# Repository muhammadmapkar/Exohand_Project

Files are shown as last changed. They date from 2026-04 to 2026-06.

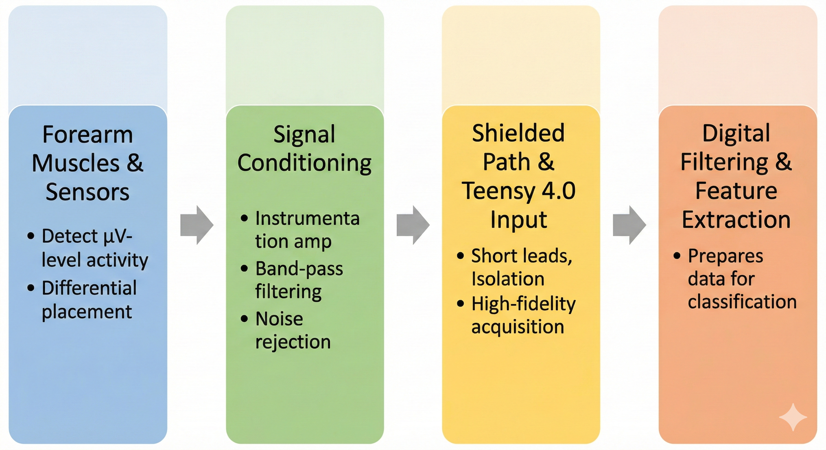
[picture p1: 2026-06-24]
media/Gemini_Generated_Image_888kaw888kaw888k.png

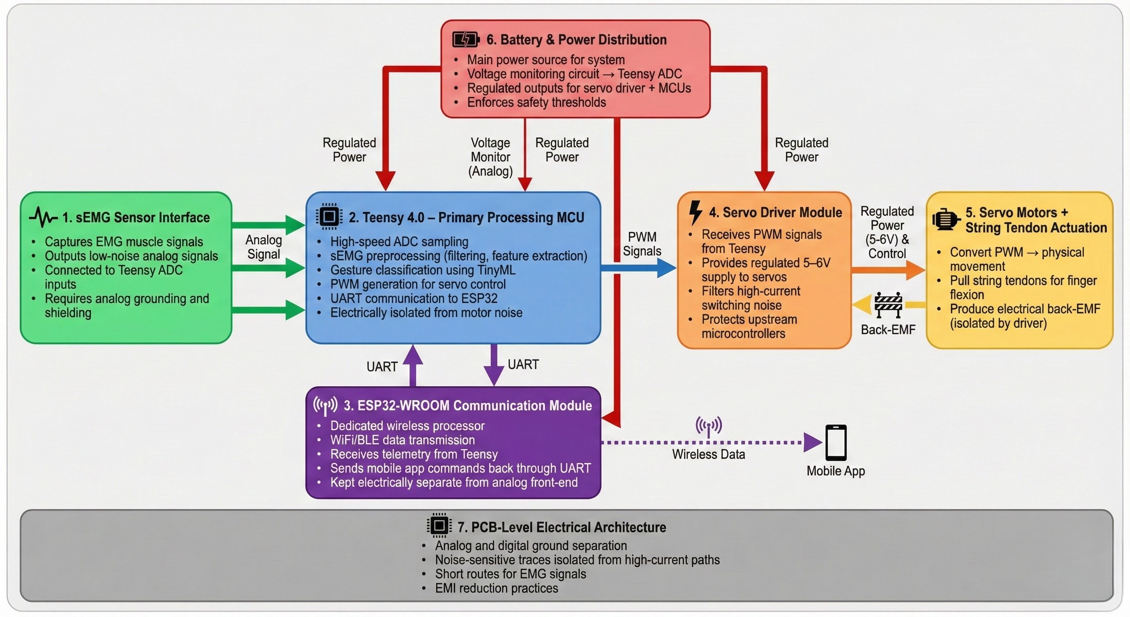
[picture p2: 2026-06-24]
media/Gemini_Generated_Image_9dc1pz9dc1pz9dc1~2.jpg

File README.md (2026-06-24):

# ExoHand

EMG-controlled assistive robotic hand. Built for ECTE351 by Team Orvyn (Group 19).

## Overview

ExoHand reads surface EMG (sEMG) from the forearm, classifies the muscle activity into a hand gesture, and drives four servo-actuated fingers to match. The current system recognizes `rest`, `fist`, and individual-finger gestures (`pinky&ring`, `middle`, `index`, `thumb`), running the trained classifier directly on the microcontroller. VR integration is planned; not yet in this codebase. — see `docs/architecture.md`. Runs the trained classifier on-device (no PC needed for inference).

## EMG-control concept

1. Sample raw EMG at 1 kHz from a single sensor channel.
2. Extract statistical features (MAV, RMS, variance, std dev, waveform length, zero-crossing rate, slope sign changes, skewness, kurtosis, IQR) over a rolling 30-sample window.
3. Classify the window with a Random Forest trained on EMG collected by the team (plus validation against the public NinaPro benchmark dataset).
4. Debounce the result (4 agreeing windows + 150ms hold) before committing to a new gesture.
5. Drive 4 servos through a PCA9685 to match the confirmed gesture, moving smoothly rather than snapping.

Full signal-flow diagram: `docs/architecture.md`.

## Hardware stack

- Teensy 4.0 — main MCU for EMG sampling, feature extraction, and on-device RF inference
- PCA9685 servo driver (I2C, 4 channels)
- MG996R servos (or equivalent)
- SEN0240 EMG sensor
- ESP32-C3, for live telemetry/graph relay (`firmware/current/esp32_bridge.ino` — self-hosted WiFi AP + WebSocket server)

## Repo layout

```
exohand/
├── firmware/        Teensy/ESP32 .ino code — current/ is what's in active use, archive/ is superseded versions
├── web/             static site + the FastAPI live dashboard
├── hardware/        KiCad schematics/PCB, BOM, perfboard build docs
├── signal-processing/  EMG filtering, feature extraction, trained model, datasets
├── docs/            build-log, architecture, decisions, posters
└── media/           screenshots, recordings, concept art
```

Nothing failed or superseded was deleted — old firmware versions, every dated PCB backup, duplicate dataset exports, and earlier notebook runs are all kept under the relevant `archive/` folders. See `docs/build-log.md` for the full story of what was tried and what changed.

## How to build / run

**Firmware:** open `firmware/current/teensy_final.ino` in Arduino IDE with Teensyduino (board: Teensy 4.0), plus the Adafruit PWM Servo Driver and Watchdog_t4 libraries. It includes `ai_classifier_model.h`, which is checked into `firmware/current/` and compiles as-is. To regenerate it from a retrained model, run `python3 signal-processing/export_model_to_header.py` (loads `ExoHand_RF_Model.joblib` + `ExoHand_Scaler.joblib`, writes the header back to `firmware/current/ai_classifier_model.h`).

**Signal processing / training:** `pip install -r signal-processing/requirements.txt`, then `signal-processing/ExoHand_EMG_Classifier_RF_V2.ipynb` to retrain, or `signal-processing/live_predict.py` to run live PC-side inference over serial.

**Live dashboard:** `web/dashboard/app.py` (FastAPI). Install `web/dashboard/requirements.txt`, run with `uvicorn app:app`, open the browser page it serves. Includes a `/api/demo` mode that fakes EMG data if no hardware is connected.

**Website:** `web/website.html` is the current main site (Live Rehab dashboard view, live EMG chart, camera-based sensor-placement assistant). `web/archive/ORVYNUpdated.html` is an earlier, less developed version.

**Hardware:** schematics and PCB in `hardware/schematics/`, BOM in `hardware/bom/`, perfboard wiring/assembly in `hardware/perfboard/`.

## Credit

Team Orvyn (Group 19). My role: led firmware (Teensy), EMG signal processing, hardware build. Data collection was team effort. Benchmark data from NinaPro.

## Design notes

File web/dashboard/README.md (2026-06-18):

# ExoHand Live EMG Gesture Dashboard

Real-time browser-based dashboard that reads EMG signals from a **Teensy 4.0** via serial, classifies hand gestures using a pre-trained **Random Forest** model, and displays predictions live — no terminal interaction required.





---

## 📁 File Structure

```
ExoHand_Live_Dashboard/
├── app.py                        ← FastAPI backend (serial + model + WebSocket)
├── requirements.txt              ← Python dependencies
├── templates/
│   └── index.html                ← Dashboard HTML
├── static/
│   ├── style.css                 ← Dark theme CSS
│   └── app.js                    ← Frontend logic + Chart.js
├── README.md                     ← This file
│
│  (Place these model files here or in the parent directory)
├── ExoHand_RF_Model.joblib       ← Trained Random Forest model
└── ExoHand_Scaler.joblib         ← EMG Input Scaler
```

---

## 1. Place the Model Files

Copy these three `.pkl` files (exported from Google Colab) into **this folder** or its **parent folder**:

| File | Purpose |
|---|---|
| `ExoHand_RF_Model.joblib` | Trained Random Forest classifier |
| `ExoHand_Scaler.joblib` | EMG Input Scaler |

---

## 2. Install Requirements

Open a terminal in this directory and run:

```bash
pip install -r requirements.txt
```

This installs: `fastapi`, `uvicorn`, `websockets`, `pyserial`, `numpy`, `pandas`, `scikit-learn`, `joblib`, `jinja2`.

---

## 3. Upload Teensy Arduino Code

Flash the following code to your **Teensy 4.0** using the Arduino IDE:

```cpp
const int EMG_PIN = A0;

int baseline = 0;

void setup() {
  Serial.begin(115200);

  long total = 0;

  for (int i = 0; i < 500; i++) {
    total += analogRead(EMG_PIN);
    delay(1);
  }

  baseline = total / 500;
}

void loop() {
  int raw = analogRead(EMG_PIN);
  int signal = abs(raw - baseline);

  Serial.println(signal);

  delay(20);
}
```

### What this does:
- Reads the EMG sensor on analog pin **A0**
- Calibrates a baseline from the first 500 samples
- Sends `abs(raw - baseline)` over serial at **115200 baud**
- One numeric value per line, ~50 samples/second (20 ms delay)

---

## 4. Close the Arduino Serial Monitor

> ⚠ **Only one application can access a serial port at a time.**

Before running the dashboard, **close the Arduino Serial Monitor** (or any other program using the serial port). Otherwise the dashboard will fail to connect.

---

## 5. Run the Dashboard

```bash
python app.py
```

Then open your browser at:

```
http://127.0.0.1:8000
```

You should see the ExoHand Live EMG Gesture Dashboard.

---

## 6. Using the Dashboard

1. **Refresh Ports** — Click 🔄 Refresh to detect available serial ports.
2. **Select Port** — Choose the Teensy serial port from the dropdown (e.g. `/dev/cu.usbmodem14101` on macOS).
3. **Connect** — Click ▶ Connect. The dashboard starts reading live EMG data.
4. **Watch Predictions** — The prediction card updates in real time with the classified gesture, confidence percentage, and a colour-coded display.
5. **Live Graph** — The EMG signal chart shows the last 200 samples continuously.
6. **Gesture History** — The last 10 gesture changes are shown with timestamps and confidence.
7. **Disconnect** — Click ■ Disconnect when done.

---

## Demo Mode (No Hardware Required)

If you don't have the Teensy connected, click the **🎮 Demo Mode** button in the connection panel. This generates fake EMG data at ~50 Hz and runs it through the real Random Forest model, so you can verify that the graph, prediction card, gesture history, and all UI elements work correctly.

---

## 7. Troubleshooting

| Problem | Solution |
|---|---|
| **"Could not open port"** | Close the Arduino Serial Monitor. Only one app can use a serial port. |
| **No ports listed** | Check that the Teensy is plugged in via USB. Click 🔄 Refresh. |
| **"Model not found"** | Make sure the `.pkl` files are in this folder or its parent folder. |
| **Graph shows no data** | Ensure the Teensy code is uploaded and printing values. Check baud rate (115200). |
| **Predictions say "Calibrating"** | Wait for 25 samples to fill the sliding window (~0.5 seconds). |
| **Predictions seem wrong** | The model was trained on specific gestures. Ensure your EMG sensor placement matches training conditions. |
| **WebSocket disconnects** | The dashboard auto-reconnects. If persistent, restart `app.py`. |
| **Import errors** | Run `pip install -r requirements.txt` again. |
| **Port permission denied (Linux)** | Run `sudo chmod 666 /dev/ttyACM0` or add your user to the `dialout` group. |
| **Port busy error** | The Arduino Serial Monitor is still open. Close it and try again. |

---

## Diagnostic Endpoints

| Endpoint | Method | Description |
|---|---|---|
| `/api/ports` | GET | List available serial ports |
| `/api/connect` | POST | Connect to a serial port (`{"port": "...", "baud": 115200}`) |
| `/api/disconnect` | POST | Disconnect from the serial port |
| `/api/demo` | POST | Start demo mode (fake EMG data) |
| `/api/test-serial` | GET | Read 10 raw serial values and return them as JSON (for debugging) |
| `/ws/live` | WebSocket | Live EMG + prediction data stream |

---

## Technical Details
 
 - **Sliding window**: 30 samples (~0.6 s at 50 Hz)
 - **Prediction trigger**: Every 5 new samples
 - **Smoothing**: Majority vote over the last 5 predictions
 - **Features extracted**: `MAV`, `RMS`, `Variance`, `Std`, `WL`, `ZCR`, `SSC`, `Skew`, `Kurtosis`, `IQR`
 - **Gestures**: `fist`, `index`, `middle`, `pinky&ring`, `rest`, `thumb`
 - **Backend → Frontend**: WebSocket at `/ws/live` streaming JSON at ~50 Hz

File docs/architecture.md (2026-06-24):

# Architecture

## Signal flow (EMG → Teensy → PCA9685 → servos)

```mermaid
flowchart LR
    EMG["sEMG sensor (SEN0240)\non Teensy A0"] -->|"1 kHz sampling\n(IntervalTimer ISR)"| BUF["30-sample\nrolling window"]
    BUF --> FEAT["Feature extraction\nMAV, RMS, Variance, Std,\nWL, ZCR, SSC, Skew, Kurtosis, IQR"]
    FEAT --> RF["Embedded Random Forest\n(ai_classifier_model.h)\nmajority vote across trees"]
    RF --> DEBOUNCE["Debounce\n(4 agreeing windows,\n150ms min hold)"]
    DEBOUNCE --> GESTURE["Confirmed gesture\nrest / fist / pinky&ring /\nmiddle / index / thumb"]
    GESTURE --> SERVO["Servo target angles\n(4 channels)"]
    SERVO --> PCA["PCA9685 (I2C, 0x40)\n50 Hz PWM"]
    PCA --> M1["Servo: pinky & ring"]
    PCA --> M2["Servo: middle"]
    PCA --> M3["Servo: index"]
    PCA --> M4["Servo: thumb"]
    DEBOUNCE -->|"UART1, 115200 baud"| ESP["ESP32-C3\n(live graph relay)"]
    BUF -->|"raw EMG, every 20ms"| ESP
```

## Two parallel inference paths

The project has two separate ways of running the trained classifier, built at different times and not unified:

```mermaid
flowchart TB
    subgraph training["Offline training (notebook)"]
        DATA["Team-collected EMG\n(datasets/collected)\n+ NinaPro benchmark\n(datasets/benchmark)"] --> NB["ExoHand_EMG_Classifier_RF_V2.ipynb"]
        NB --> MODEL["ExoHand_RF_Model.joblib\nExoHand_Scaler.joblib"]
    end

    subgraph onboard["On-device (current firmware)"]
        MODEL -.->|"converted to C arrays\n(conversion step not saved)"| HDR["ai_classifier_model.h\n(missing from repo)"]
        HDR --> TEENSY["ExoHand_Teensy.ino\nruns RF inference on-chip"]
    end

    subgraph offboard["PC-side (dev/demo tool)"]
        MODEL --> LP["live_predict.py /\nFastAPI dashboard app.py"]
        SERIAL["Serial: raw EMG from Teensy"] --> LP
        LP --> DASH["Browser dashboard\n(WebSocket live graph)"]
    end
```

The on-device path (`ExoHand_Teensy.ino`) is the intended final form — the Teensy classifies and drives servos with no PC required. The PC-side path (`live_predict.py`, the FastAPI dashboard) is a development and demo tool that reads raw EMG over serial and classifies on a laptop instead, useful for visualizing the live signal and testing the model before/without embedding it.

## Hardware stack

- **MCU:** Teensy 4.0
- **Servo driver:** PCA9685, I2C address `0x40`, 50 Hz PWM
- **Servos:** MG996R (or equivalent), 4 channels — pinky&ring, middle, index, thumb
- **EMG sensor:** SEN0240, single analog channel on Teensy `A0` in the current firmware (earlier firmware used 3 channels: flexor/extensor/extra)
- **Wireless telemetry:** ESP32-C3 running `esp32_bridge.ino` — a self-hosted WiFi access point (SSID `ExoHand_Live`) plus a WebSocket server (port 81) that relays serial lines from the Teensy straight to a connected browser. `ExoHand_ESP32.ino`/`ExoHand_ServoTest.ino` are separate servo-test sketches for the ESP32/Teensy side, not the telemetry bridge itself.
- **Power:** 7.4V 2S LiPo, stepped down for servo and logic rails (per project README notes)

## VR integration

A VR integration goal is part of the project's stated direction, but no VR-specific code was found in the files reviewed here. Treat this as a future goal, not a built feature. (Note: `website.html` does include a camera-based "placement" assistant using MediaPipe FaceMesh — a 2D face-landmark guide, likely for sensor placement on the arm/face via webcam. This is AR-adjacent tooling, not a VR integration, and is unrelated to the stated VR goal.)

## Signal processing pipeline (current, on team-collected + benchmark data)

1. Sample EMG at 1000 Hz.
2. Maintain a 30-sample rolling window, advancing in steps of 5 samples.
3. Extract 10 features per window: MAV (scaled), RMS, variance, standard deviation, waveform length, zero-crossing rate, slope sign changes, skewness, kurtosis, IQR.
4. Classify with a Random Forest (hard majority vote across trees).
5. Debounce: require 4 consecutive windows to agree, plus a minimum 150ms hold, before changing the confirmed gesture.
6. Map confirmed gesture to per-finger servo open/closed targets, moving smoothly (3°/step, every 15ms) rather than snapping.

An earlier, simpler pipeline (`Filter_signals.py`, `Exohand_emg_with_filter.ino`) used a 20–450 Hz bandpass filter + 50 Hz notch filter + RMS thresholding for binary rest/active detection, validated against the public NinaPro benchmark dataset. This was the proof-of-concept before moving to the multi-class, team-data-trained classifier described above.

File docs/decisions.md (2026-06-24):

# Key Decisions

**Random Forest over a neural network for gesture classification.** The classifier needed to run on a Teensy MCU with no OS and no heavy ML runtime. A trained Random Forest can be converted into plain C arrays (tree nodes, thresholds, leaf classes) and run as simple `if`/`else` comparisons — no matrix math, no floating-point-heavy inference engine. This is why `ExoHand_Teensy.ino` runs inference as a hard-coded tree-walk (`predictTree` / `classify`) instead of calling out to a model file at runtime.

**Move from single-servo RMS-threshold control to multi-class, multi-finger classification.** The earliest firmware (`Exohand_emg_with_filter.ino`, `exohand_emg_test.ino`) drove one servo based on whether RMS crossed a fixed threshold — workable for a binary "fist or not" gesture, not for isolating individual fingers. The later pipeline (10 hand-engineered features → Random Forest → 4 independent servo channels) was the response to that limitation, trading simplicity for the ability to recognize `rest`, `fist`, and individual-finger gestures (`pinky&ring`, `middle`, `index`, `thumb`).

**Validate the filtering pipeline against a public benchmark before trusting team-collected data.** `Filter_signals.py` was first run against the NinaPro public EMG dataset (`datasets/benchmark`), not the team's own recordings. This let the bandpass/notch/RMS pipeline be checked against known-good reference data before relying on it for the team's own multi-person EMG dataset (`datasets/collected`), which has no independent ground truth to check against.

**Debounce the classifier output rather than act on every window.** A single 30-sample window classification is noisy — `ExoHand_Teensy.ino` requires 4 consecutive windows to agree on the same gesture, plus a 150ms minimum hold time, before changing the servo targets. This trades a small amount of latency for fewer false gesture-switches.

**Smooth servo motion instead of snapping to target angle.** Servos step 3° every 15ms toward their target rather than jumping immediately. This was likely a response to current-spike / mechanical-jolt issues noted as a known challenge in the project README (servo current spikes causing voltage drops).

**PCA9685 I2C driver instead of driving servos directly from MCU PWM pins.** Four servos need four independent PWM channels; routing them through a dedicated I2C PWM driver frees up MCU pins and offloads PWM generation, at the cost of an extra I2C peripheral and address (`0x40`) to manage.

**ESP32-C3 for wireless telemetry instead of adding WiFi logic to the Teensy.** The Teensy handles real-time sampling and inference; UART-bridging the result to a separate ESP32 keeps WiFi/networking code off the time-critical MCU. `esp32_bridge.ino` implements this: it puts the ESP32 into its own WiFi access-point mode and runs a WebSocket server, forwarding lines read from the Teensy over `Serial2` straight to a browser. This is a self-hosted AP rather than joining an existing network, so the dashboard/website has to connect to the ESP32's own WiFi to receive live data — a reasonable choice for a standalone demo, but worth knowing if internet-connected logging is ever needed.

**Custom PCB attempted, perfboard used for the actual build.** The KiCad project went through 20 dated backup snapshots over roughly five months (Nov 2025–Jun 2026), splitting logic and power planes per the design notes. Given the time spent, the team also produced perfboard assembly guides and wiring documentation in parallel — the perfboard appears to be how the hardware was actually built and wired, with the PCB design kept as the longer-term/parallel hardware effort rather than abandoned.

**Keep a PC-side prediction path (`live_predict.py`, the FastAPI dashboard) alongside the on-device firmware.** Running inference on a laptop over serial is slower and requires a tethered connection, but it's much easier to debug and visualize than reading values off an embedded device — useful during development and for the live demo, even though the end goal is fully on-device classification.

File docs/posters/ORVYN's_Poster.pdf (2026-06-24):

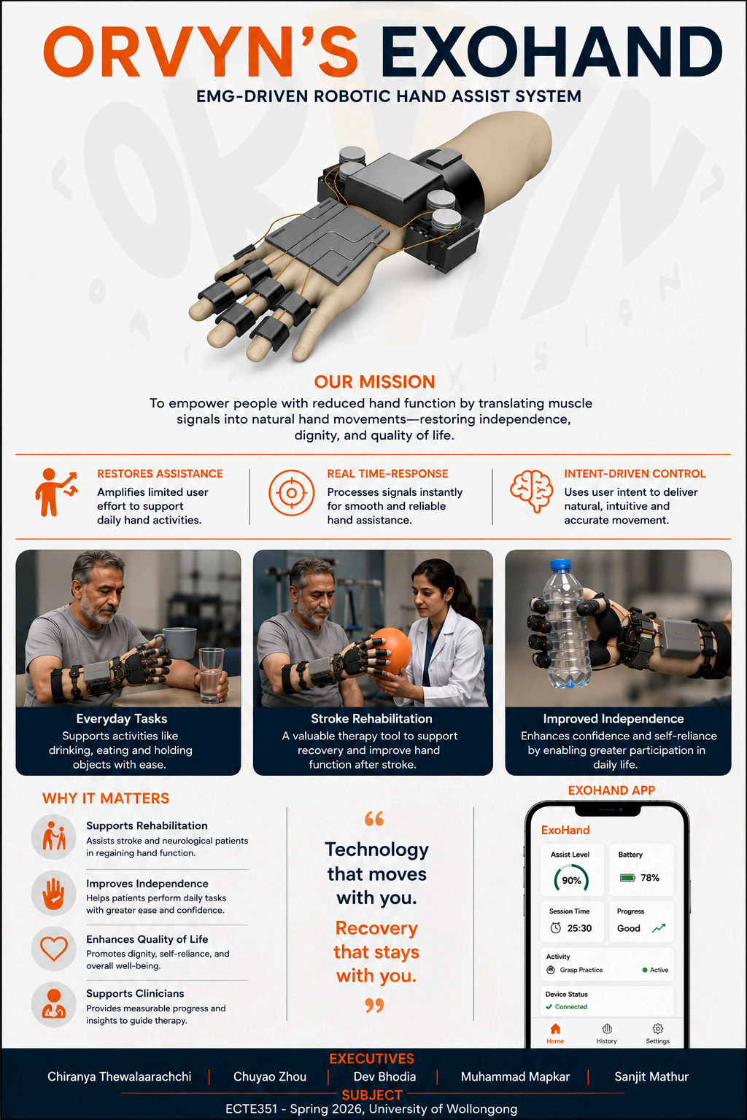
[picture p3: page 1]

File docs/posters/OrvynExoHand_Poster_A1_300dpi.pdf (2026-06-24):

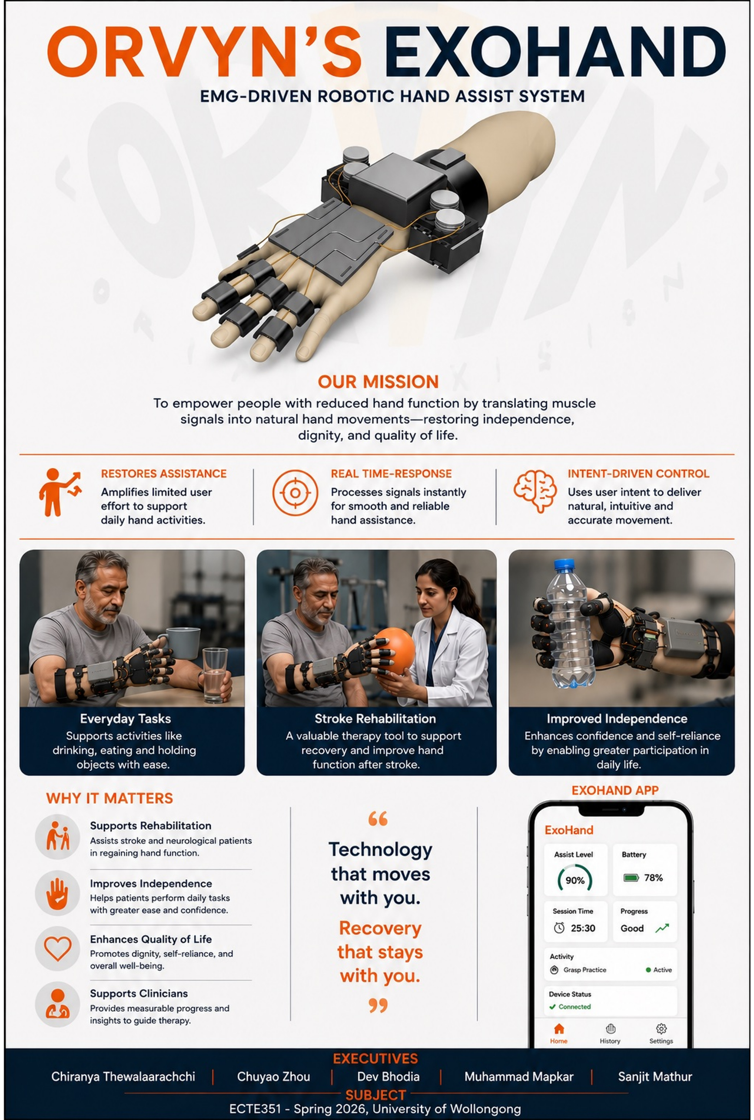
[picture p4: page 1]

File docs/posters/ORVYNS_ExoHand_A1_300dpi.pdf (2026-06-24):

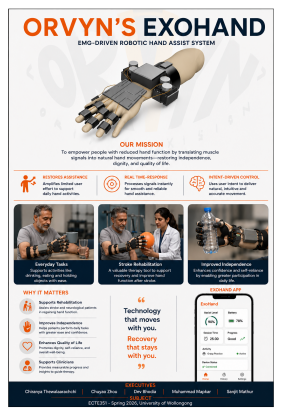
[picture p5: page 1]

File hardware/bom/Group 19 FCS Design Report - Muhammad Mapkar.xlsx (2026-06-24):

 |  | Max mark =30 | Dev | Chuyao | Muhammad | Sanjit | Chiranya
 |  |  | Bhodia | Zhou | Mapkar | Mathur | Thewalaarachchi | Total =100
Name of Person submitting | Dev | Bhodia | 20 | 20 | 20 | 20 | 20 | 100
 | Muhammad | Mapkar | 20 | 20 | 20 | 20 | 20 | 100
 | Chuyao | Zhou | 20 | 20 | 20 | 20 | 20 | 100
 | Sanjit | Mathur | 20 | 20 | 20 | 20 | 20 | 100
 | Chiranya | Thewalaarachchi | 20 | 20 | 20 | 20 | 20 | 100

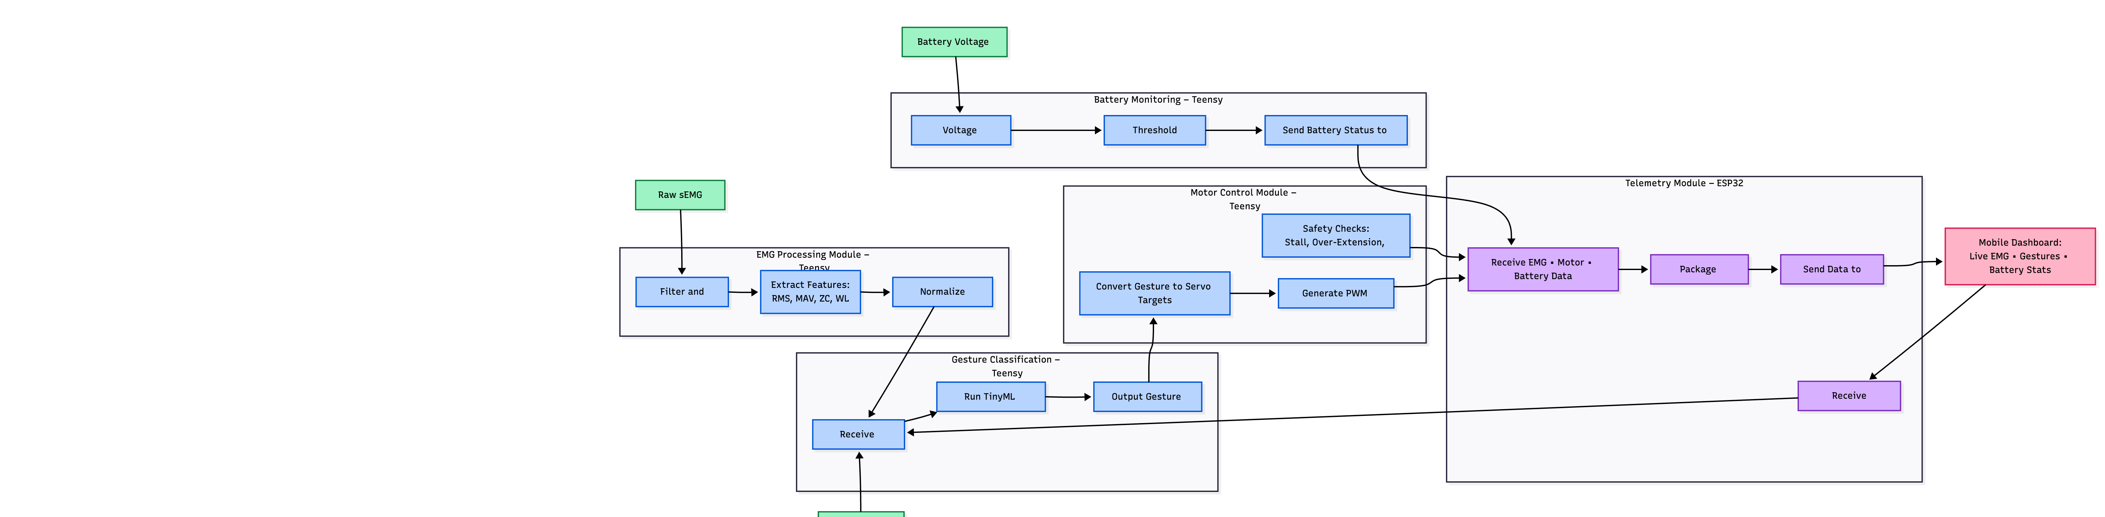
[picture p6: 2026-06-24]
media/Untitled diagram-2025-12-04-155013.png

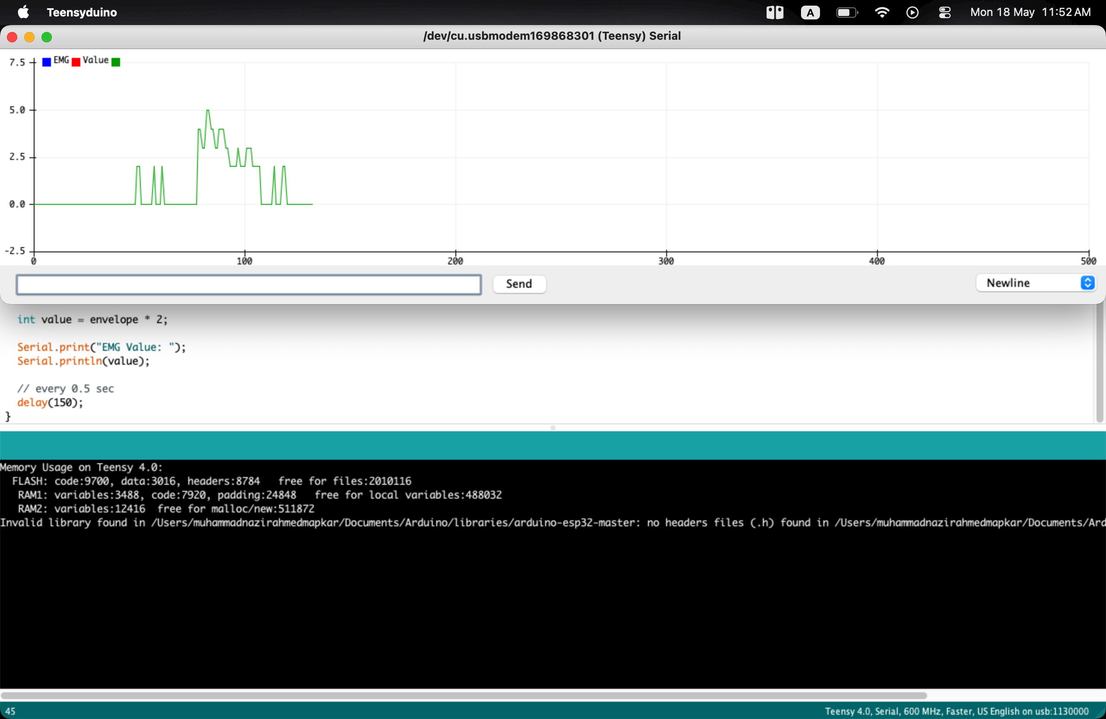
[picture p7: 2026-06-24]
media/Screenshot 2026-05-18 at 11.52.37 AM.png

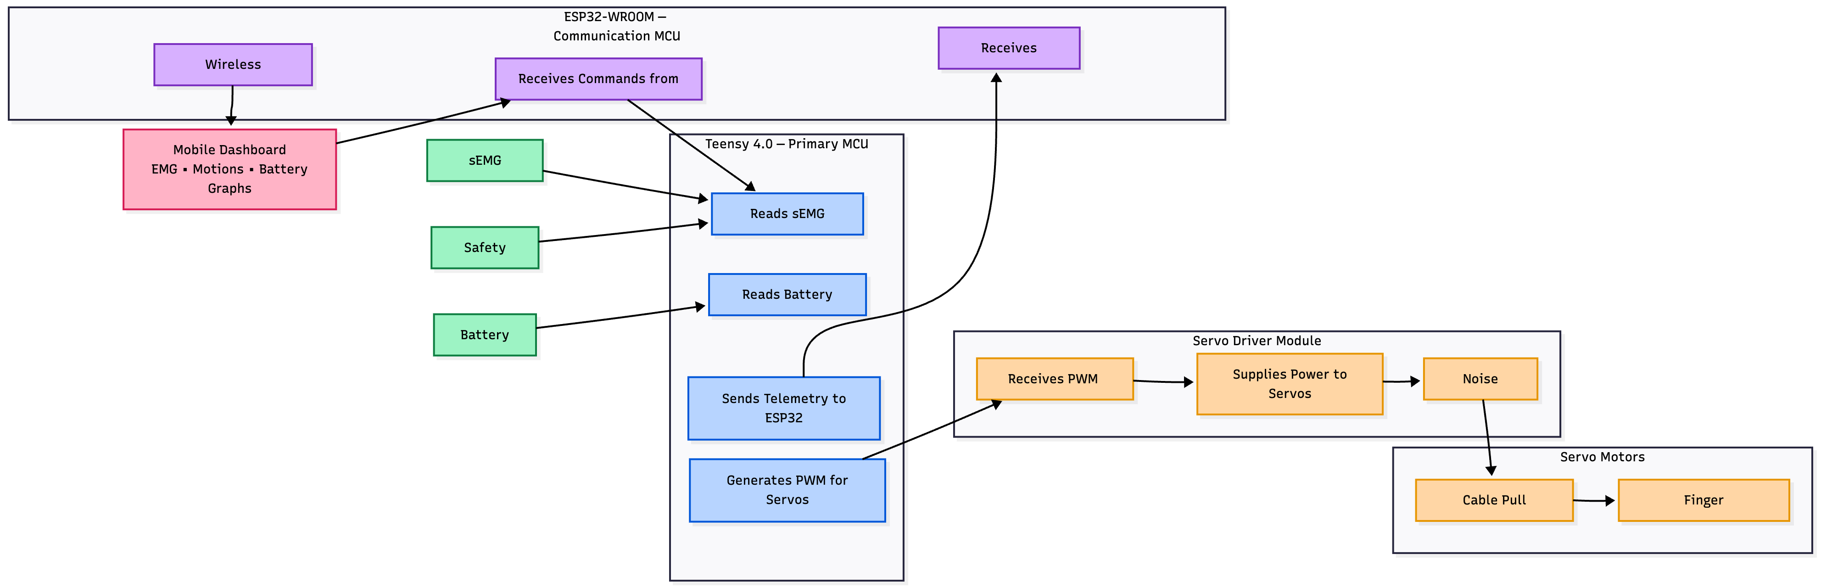
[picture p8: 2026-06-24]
media/Untitled diagram-2025-12-04-135625.png

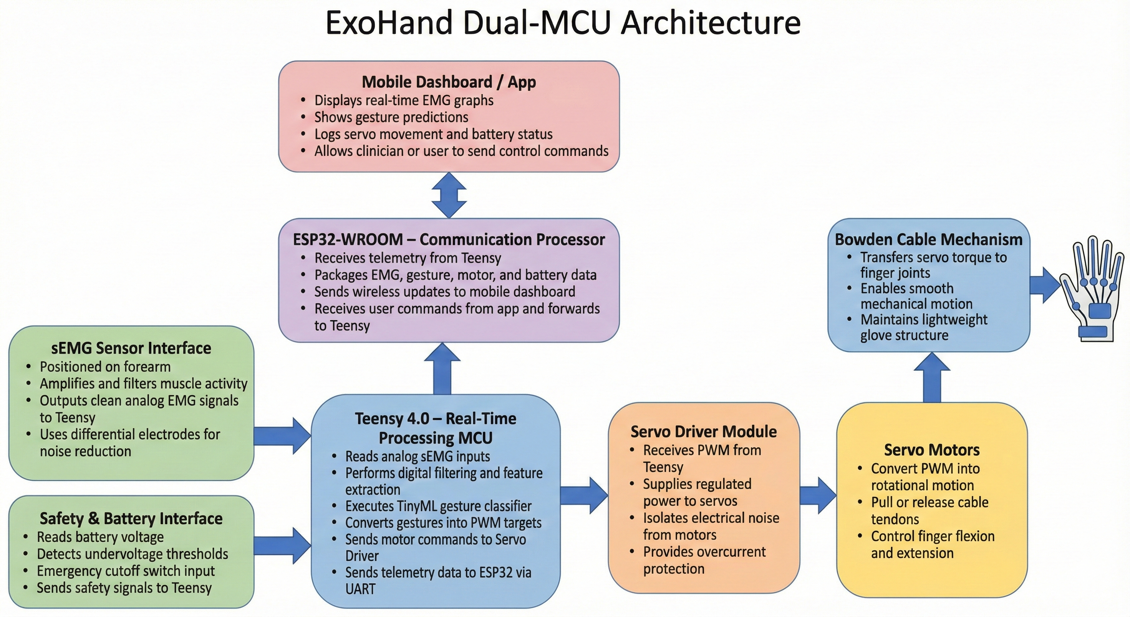
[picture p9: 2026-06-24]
media/Gemini_Generated_Image_gel79egel79egel7.png

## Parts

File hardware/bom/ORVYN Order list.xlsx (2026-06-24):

Team | Item name | Quantity | Price per unit | Total | Shipping cost | Link | Source | Alternative link | Comments
ORVYN | ESP32 Development Board | 1 | 35 | 35 | 15 | https://besomi.com/ae_en/esp32-wifibluetooth-development-board.html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 | Besomi | https://www.amazon.ae/ESP-WROOM-32-Development-Microcontroller-Integrated-Compatible/dp/B07WCG1PLV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 | Besomi free shipping for local orders more than AED100
ORVYN | MG996R Servo Motor | 2 | 49 | 98 | 0 | https://www.amazon.ae/Reland-Sun-MG996R-Torque-Digital/dp/B0D132YH7P?mcid=92f6d3b8d37335389e200cfe385ba95d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 | Amazon | https://www.amazon.ae/ETMall-Digital-Compatible-Arduino-Raspberry/dp/B08CH2SJLR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 | We need 5 motors in total
ORVYN | Sensor Shield | 1 | 53 | 53 | included in item cost | https://www.amazon.ae/DIYmall-Expansion-DEVKIT-ESP32-WROOM-32-Development/dp/B0CM94BYWB | Amazon |  | Alternate would be Custom PCB Design
ORVYN | Servo Motor Driver | 1 | 26 | 26 | 0 | https://www.amazon.ae/UIOTEC-PCA9685-Channel-12-Bit-Arduino/dp/B07F143YG7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 | Amazon | https://www.blue-pcb.com/products/16-channel-12-bit-pwm-servo-driver-i2c-interface-pca9685-module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 | -
ORVYN | EMG Sensors | 3 | 80 | 240 | 0 | https://www.blue-pcb.com/products/diy-emg-muscle-signal-sensor-kit-with-professional-emg-cable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 | Blue pcb | not available | free shipping for orders more than AED100
ORVYN | LiPo Battery | 1 | 90 | 90 | 15 | https://besomi.com/ae_en/2s-2200mah-45c.html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 | Besomi | not available | -
ORVYN | DC-DC buck converter | 1 | 19 | 19 | 0 | https://www.amazon.ae/XL4015-Converter-Lithium-Battery-Charging/dp/B0FGCTZZRC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 | Amazon | not available | -
ORVYN | Rocker Switch | 5 | 2 | 10 | 15 | https://besomi.com/ae_en/kcd1-101-rocker-switch16a-250vacon-off-black.html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 | Besomi | not available | -
ORVYN | Jumper Wires | 1 | 20 | 20 | 15 | https://besomi.com/ae_en/premium-dupont-wire-kit-for-arduino-and-diy-projects-120pcs-20cm-multicolored.html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 | Besomi | not available | -
ORVYN | Velcro straps | 1 | 19 | 19 | 0 | https://www.amazon.ae/ECVV-Fastening-Organizer-Electronics-Accessories/dp/B0BX9TKSW6 | Amazon | https://www.amazon.ae/QITELE-Management-Fastening-Reusable-Organizer/dp/B08SGCWW97 | -
ORVYN | PETG filament | 1 | 81 | 81 | 0 | https://www.amazon.ae/ELEGOO-Gray-Dimensional-1kg-Cardboard/dp/B0F7LFTKLJ | Amazon | https://www.amazon.ae/dp/B0F9WKV38Y?aref=XRrMGZpS2i&sp_csd=d2lkZ2V0TmFtZT1zcF9kZXRhaWw | available in univeristy?
ORVYN | Kevlar rope | 1 | 54 | 54 | 0 | https://www.amazon.ae/9KM-DWLIFE-Strength-Retardant-Ridgeline/dp/B0B1WKH21R?adgrpid=131346172498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 | Amazon | https://www.amazon.ae/9KM-DWLIFE-Strength-Resistant-Survival/dp/B0BGGC92PQ | -
ORVYN | Resistors??? | 2 | 0 | 0
ORVYN |  |  |  | 0
ORVYN |  |  |  | 0
 |  |  |  | 0
 |  |  |  | 0
 |  | Total: |  | 745

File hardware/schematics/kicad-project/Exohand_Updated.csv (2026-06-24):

Reference | Qty | Value | DNP | Exclude from BOM | Exclude from Board | Footprint | Datasheet
C1 | 1 | 0.1µF |  |  |  | Capacitor_SMD:C_0805_2012Metric | ~
J1,J2,J3 | 3 | Conn_01x06_Pin |  |  |  | Connector_PinHeader_2.54mm:PinHeader_1x06_P2.54mm_Vertical | ~
JBAT1 | 1 | Conn_01x02 |  |  |  | Connector_JST:JST_XH_B2B-XH-A_1x02_P2.50mm_Vertical | ~
R1 | 1 | 100kΩ |  |  |  | Resistor_SMD:R_0805_2012Metric | ~
R2 | 1 | 47kΩ |  |  |  | Resistor_SMD:R_0805_2012Metric | ~
Servo1,Servo2,Servo3,Servo4,Servo5 | 5 | Conn_01x03 |  |  |  | Connector:FanPinHeader_1x03_P2.54mm_Vertical | ~
U2 | 1 | PCA9685PW |  |  |  | Package_SO:TSSOP-28_4.4x9.7mm_P0.65mm | http://www.nxp.com/docs/en/data-sheet/PCA9685.pdf
U3 | 1 | Teensy4.0
U4 | 1 | ESP32-C3-DevKitM-1 |  |  |  | RF_Module:ESP32-C3-DevKitM-1 | https://docs.espressif.com/projects/esp-idf/en/latest/esp32c3/hw-reference/esp32c3/user-guide-devkitm-1.html

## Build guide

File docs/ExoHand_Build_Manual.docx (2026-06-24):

ExoHand

Perfboard Build Manual

Step by step. Brick by brick. No prior skill needed.

Read this top to bottom. Do not skip. Each module builds on last one. Box ticks mean you stop and check before next step.

# Module 0 – The Plan

You build hand controller on perfboard. No PCB. Perfboard is enough for demo.

Big idea: plug, do not glue chips. Sockets hold modules. Module dies, you swap it. No resolder.

Golden Rule

Socket everything.

Never solder Teensy, WEMOS, or PCA9685 straight to board.

Use female headers. Modules drop in. Pull out if dead.

# Module 1 – Your Bricks

Lay these out first. Confirm each one in hand.

Brick | What it is | How many
Teensy 4.0 | Main brain board | 1
WEMOS C3 Mini | Wi-Fi helper board | 1
PCA9685 | Servo driver chip | 1 (not in schematic yet)
EMG channels | Muscle signal inputs | 3
Servo connectors | Motor plugs | 4
Buck / battery nets | Power supply lines | as drawn
I2C bus | Two-wire chat line | 1

Missing brick

PCA9685 not in schematic yet.

Add it. It drives 4 servos over I2C.

Without it, servos do not move.

# Module 2 – Your Tools

- Soldering iron. Hot tip melts metal glue.
- Solder wire. The metal glue.
- Perfboard. Grid board with holes.
- Female headers. Plastic strips with sockets.
- DIP adapter. Small carrier board for PCA9685.
- Screw terminals or 3-pin headers. For servo plugs.
- Solid copper wire. For power rails.
- Hot glue gun. For holding wires down.

# Module 3 – Build It

## Step group A – Power rails

1. Pick three rows along board edge.
2. Run one solid copper wire down each. These are buses.
3. Name them: VBAT rail, 5V rail, GND rail.
4. Solder wire flat to copper. Long lines, no gaps.

Why rails

Bus = shared power line.

Every module taps same rail.

Clean rails stop random resets.

## Step group B – Sockets

5. Place female headers where each module sits.
6. Solder headers only. Not the modules.
7. Solder PCA9685 onto DIP adapter once.
8. Plug DIP adapter into its socket on board.

Now Teensy, WEMOS, and PCA9685 all drop into sockets. None soldered direct.

## Step group C – Servos

9. Add screw terminals or 3-pin headers for 4 servos.
10. No loose jumper wires for servos. They pull free.
11. Each servo: signal, 5V, GND. Match to PCA9685 outputs.

## Step group D – Signals and I2C

12. Wire 3 EMG channels to Teensy inputs.
13. Wire I2C: two lines, SDA and SCL.
14. Connect Teensy and PCA9685 on same I2C bus.

## Step group E – Lock it down

15. Hot glue every wire that leaves the board.
16. Glue gives strain relief. Tug does not break joint.
17. Check no bare wires touch. Recheck rails.

Strain relief

A pulled wire kills a demo.

Glue blob holds wire to board.

Cheap insurance. Do it every time.

# Module 4 – 5-Day Plan

Five days. Doable. Stick to the split.

Day | Job | Done means
1 | Solder sockets. Lay power rails. | Headers fixed. Rails run.
2 | Wire signals. Glue wires down. | All links wired.
3 | Plug modules. Flash firmware. | Boards boot. I2C talks.
4 | Test EMG. Test servos. | Gesture moves hand.
5 | Stress test. Fix flaky bits. | Survives 20 runs.

# Module 5 – Faster But Risky

Breadboard option: zero soldering. Push pins into holes.

- Good: fast, no iron, easy swap.
- Bad: wires pull loose. Risky live on stage.

Verdict: perfboard wins for the fair. Use breadboard only to test early.

# Module 6 – Answer Before You Start

Tell me these. Then I tune the plan.

18. Got perfboard and headers in hand already?
19. Soldering iron available right now?
20. Demo plan: live EMG gesture, or preset motion fallback?

# Module 7 – Word Bank

Plain words for every term above.

Perfboard

Flat board full of holes. You build on it.

PCB

Custom printed board. Made in a factory. You skip this.

Female header

Plastic strip of sockets. Modules plug in.

DIP adapter

Tiny board. Holds a chip so it fits a socket.

Bus / rail

Shared wire line. Carries power or data to all.

I2C

Two-wire chat line. Chips talk over SDA and SCL.

EMG

Muscle signal. Your arm flex becomes a number.

Servo

Small motor. Moves a finger to an angle.

Strain relief

Glue or clamp. Stops a tug from breaking a joint.

Firmware

Code on the board. Tells chips what to do.

ExoHand Build Manual • Page

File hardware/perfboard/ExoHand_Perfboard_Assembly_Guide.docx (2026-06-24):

ExoHand

Perfboard Assembly Guide

A Complete, Zero-Experience, Step-by-Step Build Manual

EMG-Controlled Robotic Exoskeleton Hand

# Table of Contents

# 0. Before You Start

This guide assumes you have never soldered a circuit before and have never built electronics from scratch. Every step is written out in full. Nothing is assumed. Read the entire guide once, start to finish, before you pick up a soldering iron. Building in the wrong order is the single biggest cause of failed boards.

This guide builds the ExoHand control board on perfboard (a board full of pre-drilled holes with copper pads, NOT a breadboard, and NOT a custom PCB). Perfboard requires you to manually wire every connection, either with solder bridges or short wire jumpers. This is slower than a breadboard but far more reliable for a competition demo, since nothing falls out.

Why This Order Matters

Power wiring is built first, and tested alone, before any chip touches the board.

Each section ends with a test. Do not skip a test to save time.

A mistake found at Step 2 takes 2 minutes to fix. The same mistake found at Step 9 can mean rebuilding the whole board.

## 0.1 What You Are Building

The ExoHand control board reads a muscle signal from your forearm (EMG), decides how much you are flexing, and moves four servo motors that pull tendons in a robotic hand. The board has five sections that all connect together:

- Power section — battery, buck converter, two voltage rails (5V logic, 6V servo power), and one common ground.
- Brain section — Teensy 4.0 microcontroller, reads the EMG sensor and decides servo angles.
- Servo driver section — PCA9685 module, takes commands from the Teensy and generates the actual PWM signals that drive servos.
- Sensor section — one OYMotion analog EMG sensor (DFRobot SEN0240), reads muscle activity.
- Wireless section — WEMOS C3 Mini, broadcasts a WiFi page so you can watch the EMG signal live on a phone or laptop.

# 1. Safety First

- Never solder with the LiPo battery connected. Always build and test with a bench power supply first.
- LiPo batteries can catch fire if shorted. Keep the battery disconnected until the entire board is verified.
- Work in a ventilated area. Solder fumes should not be inhaled directly.
- Let the soldering iron tip touch only solder joints, never wires you are holding, never the battery.
- Unplug the soldering iron when not actively soldering, even for a 5-minute break.
- Servos can pinch fingers. Keep hands clear of the mechanical hand while testing motion.

# 2. Complete Parts List

Confirm you physically have every item below before starting. Running out of wire halfway through a power rail is a common beginner mistake.

Qty | Component | Notes
1 | Perfboard | At least 7cm x 9cm, with copper pads on one side.
1 | Teensy 4.0 | Main microcontroller.
1 | WEMOS C3 Mini (ESP32-C3) | Wireless module for live EMG graph.
1 | PCA9685 servo driver (HW-176 module) | Pre-built breakout board, not a bare chip.
4 | MG996R servo motors | One per finger tendon.
1 | OYMotion analog EMG sensor (DFRobot SEN0240) | Single channel, drives all 4 servos together.
1 | 2S LiPo battery | 7.4V nominal.
1 | Buck converter (adjustable output) | Steps battery voltage down to usable rail voltage.
1 | XT60 or JST battery connector pair | Matches your LiPo connector.
1 roll | 22-24 AWG hookup wire, multiple colors | Red for power, black for ground, other colors for signals.
1 | Soldering iron + stand | Fine tip, 15-30W.
1 roll | 60/40 rosin-core solder | 0.6-0.8mm diameter is easiest for beginners.
1 | Wire strippers | 22-24 AWG range.
1 | Multimeter | Must have continuity and DC voltage modes.
1 | Bench power supply (adjustable, current-limited) | Used for safe first power-on, before the LiPo.
1 | Small flathead screwdriver | For terminal blocks if used.
1 | Heat shrink tubing or electrical tape | For insulating exposed joints.
1 | Helping-hands clamp or tape | To hold wires still while soldering.

# 3. Workspace Setup

1. Work on a flat, non-flammable surface. A piece of scrap wood or a silicone mat is ideal.
2. Set the soldering iron to 320-350°C if it has a temperature dial. If not, allow 2-3 minutes to fully heat before use.
3. Lay out all components next to the perfboard, in roughly the position they will be soldered, before touching the iron. This is your map.
4. Set the multimeter to continuity mode (the symbol that looks like a sound wave) and confirm it beeps when you touch the two probes together. This confirms the meter works before you rely on it.

# 4. Perfboard Basics (Read This Even If You Skip Other Sections)

Perfboard is a grid of holes. Each hole has a small round copper pad on the underside (the side you solder from). Pads are NOT connected to each other automatically, unlike a breadboard. Every single connection between two holes must be made by you, either with a blob of solder bridging two adjacent pads, or with a short wire soldered between two pads.

### 4.1 Two Ways to Make a Connection

- Solder bridge: for two holes that are directly next to each other, you can melt a connected blob of solder between their pads. Only use this for very short, low-current connections like signal wires.
- Jumper wire: strip a short length of hookup wire, bend the bare ends into small hooks, insert through both holes from the top, then solder each end from the bottom. Use this for every power, ground, and longer signal connection.

### 4.2 Component Orientation

Insert all chips, headers, and connectors from the TOP (component side) of the board. All soldering happens from the BOTTOM (copper side). Components should sit flush against the top surface before you solder, or they will wobble and crack joints later.

### 4.3 A Good Solder Joint

A good joint looks like a small shiny volcano shape, not a ball, not a blob, and not dull/grey. Touch the iron to BOTH the pad and the wire/lead at the same time for 2-3 seconds, then feed solder into the joint (not onto the iron tip), then remove the iron. Let it cool untouched for 5 seconds.

Common Beginner Mistakes

Cold joint: dull, grey, crumbly looking solder. Usually means the iron was not hot enough or held in place long enough. Reheat and redo.

Solder bridge you didn't mean to make: two adjacent pads accidentally joined. Check under magnification or with continuity testing.

Component soldered in backwards. Check polarity markings (silkscreen, plus signs, color-coded wires) before soldering anything irreversible.

# 5. Planning the Board Layout

Before any soldering, decide where each section of the circuit will physically sit on the board. This prevents wires crossing over each other excessively and makes later debugging far easier.

Zone | Location on board | Contains
Power zone | One long edge of the board | Battery connector, buck converter, 5V rail strip, 6V rail strip, ground strip
Logic zone | Center of the board | Teensy 4.0, PCA9685 module
Wireless zone | Corner nearest an edge (for antenna clearance) | WEMOS C3 Mini
Sensor zone | Edge nearest where the EMG cable will exit the board | 3-pin header for the EMG sensor cable
Servo zone | Opposite edge from power zone | 4-pin headers (signal, V+, GND) for each of the 4 servos

Draw this layout on paper first, full size, matching your actual perfboard dimensions. Mark where each component sits. This 10-minute step prevents the most common perfboard mistake: running out of room halfway through.

# 6. Step 1 — Build the Power Rails

Build power first, and test it completely alone, with no other chip connected. A power mistake found now is harmless. The same mistake found after the Teensy is soldered in can destroy the Teensy.

## 6.1 What You Are Building

Two separate power strips made of jumper wire, running the length of the power zone:

- GND strip — one continuous run of wire, soldered to every ground point on the board. This is your single common ground.
- 5V LOGIC strip — carries 5V to the Teensy, the PCA9685 logic pin, the WEMOS, and the EMG sensor.
- 6V SERVO strip — carries 6V to the PCA9685 servo power pin only. Servos draw this through the PCA9685's V+ rail.

## 6.2 Wiring Steps

5. Solder the battery connector's two wires to the perfboard at the start of the power zone. Positive wire to one pad, negative wire to an adjacent pad. Mark these with a small dot of red (positive) and black (negative) marker or nail polish if available.
6. Solder the buck converter's input pins (IN+ and IN-) to those same two pads. IN+ to the battery positive pad, IN- to the battery negative pad.
7. Set the buck converter output BEFORE wiring anything else to it. Connect it temporarily to your bench power supply at a safe low voltage (or briefly to the battery if you must), and turn the onboard adjustment screw while measuring output with the multimeter, until it reads exactly 6.0V. Disconnect again before continuing.
8. Solder a jumper wire from the buck converter OUT+ pad to the start of your 6V SERVO strip.
9. Solder a jumper wire from the buck converter OUT- pad to the start of your GND strip.
10. You need a SEPARATE 5V LOGIC rail. If your buck converter is single-output, add a second small buck converter (or a 5V linear regulator) fed from the same 6V SERVO strip, outputting 5V into a new 5V LOGIC strip. Do not run logic directly off 6V — it can damage the Teensy and WEMOS.
11. Extend the GND strip down the full length of the power zone with jumper wire, so every future component has a nearby ground point to solder to.

## 6.3 Test Before Continuing

Power-Only Test (mandatory)

Connect ONLY the battery (or bench supply set to 7.4V, current limit at 1A).

Multimeter on the 6V SERVO strip: must read 5.8-6.2V.

Multimeter on the 5V LOGIC strip: must read 4.8-5.2V.

Multimeter between any GND point and any other GND point: must read 0V (continuity beep).

If voltage sags or the supply hits its current limit, STOP. Recheck for a solder bridge between a power pad and a ground pad before continuing.

# 7. Step 2 — Wire the PCA9685 Servo Driver

The PCA9685 (HW-176 breakout) takes simple commands from the Teensy over I2C and generates 16 independent PWM signals. You will use 4 of its 16 channels.

## 7.1 Pinout Reference

Pin | Function | Connects To
VCC | Logic power for the chip itself | 5V LOGIC strip
GND | Ground | GND strip
V+ | Power for servo motors, passed through to channel outputs | 6V SERVO strip
OE | Output Enable, active LOW | GND strip (tie permanently low)
SDA | I2C data line | Teensy pin 18
SCL | I2C clock line | Teensy pin 19
CH0-CH3 signal pins | PWM output to servos | Servo signal wires (one channel per servo)
CH0-CH3 V+/GND pins | Power feed-through to servos | Servo power and ground wires

## 7.2 Wiring Steps

12. Place the PCA9685 module flat in the logic zone, header pins facing down toward the perfboard holes.
13. Solder VCC to the 5V LOGIC strip.
14. Solder GND to the GND strip.
15. Solder V+ to the 6V SERVO strip. Confirm with multimeter this is NOT the same strip as VCC.
16. Solder OE directly to the GND strip with a short jumper. This permanently enables the outputs.
17. Leave SDA, SCL, and the channel pins unconnected for now. They get wired in later steps.

## 7.3 Test Before Continuing

PCA9685 Power Test

Power the board from the bench supply again.

Multimeter on PCA9685 VCC pin: should read 4.8-5.2V.

Multimeter on PCA9685 V+ pin: should read 5.8-6.2V.

If a small LED on the module lights up, that is normal and expected.

# 8. Step 3 — Wire the Teensy 4.0

## 8.1 Pinout Reference

Teensy Pin | Function | Connects To
VIN | 5V power input | 5V LOGIC strip
GND | Ground (use any one GND pin) | GND strip
Pin 18 (SDA) | I2C data | PCA9685 SDA
Pin 19 (SCL) | I2C clock | PCA9685 SCL
A0 | Analog input from EMG sensor | EMG sensor signal wire
Pin 0 (RX1) | UART receive | WEMOS C3 TX pin
Pin 1 (TX1) | UART transmit | WEMOS C3 RX pin

## 8.2 Wiring Steps

18. Solder two short headers or wire leads, one to VIN, one to a GND pin, both running to the respective power strips.
19. Solder a jumper from Teensy pin 18 to PCA9685 SDA.
20. Solder a jumper from Teensy pin 19 to PCA9685 SCL.
21. Add one 4.7k ohm pull-up resistor from SDA to the 5V LOGIC strip, and one 4.7k ohm pull-up resistor from SCL to the 5V LOGIC strip. Many PCA9685 breakouts already include these onboard; check your module's silkscreen or datasheet. If unsure, add them anyway — extra pull-ups in this range do not cause harm.
22. Leave A0, pin 0, and pin 1 unconnected for now.

## 8.3 Test Before Continuing

I2C Communication Test

Power the board from the bench supply.

Connect the Teensy to your computer with USB.

Upload a basic I2C scanner sketch (search 'Arduino I2C scanner example' if you don't already have one).

Open the Serial Monitor. You must see address 0x40 reported. That is the PCA9685.

If nothing is found, double check SDA/SCL are not swapped, and that GND is truly common between Teensy and PCA9685.

# 9. Step 4 — Wire the WEMOS C3 Mini

WEMOS Pin | Function | Connects To
VBus / 5V | Power input | 5V LOGIC strip
GND | Ground | GND strip
TX | Serial transmit | Teensy pin 0 (RX1)
RX | Serial receive | Teensy pin 1 (TX1)

Important: Cross the Wires

TX always connects to RX, and RX always connects to TX, never TX-to-TX.

If the Teensy and WEMOS cannot talk to each other later, this is the first thing to recheck.

23. Place the WEMOS in the wireless zone, away from servo wiring (servo motors can introduce electrical noise that affects WiFi).
24. Solder VBus to the 5V LOGIC strip.
25. Solder GND to the GND strip.
26. Solder TX to Teensy pin 0 (RX1).
27. Solder RX to Teensy pin 1 (TX1).

# 10. Step 5 — Wire the EMG Sensor

This board uses one OYMotion analog EMG sensor (DFRobot SEN0240). It outputs a raw analog signal centered at 1.5V, swinging between 0V and 3.0V depending on muscle activity. One sensor drives all four servos together — they all move to the same angle based on a single flex signal.

Sensor Pin | Function | Connects To
VCC | Power, 3.3-5.5V accepted | 5V LOGIC strip
GND | Ground | GND strip
SIG (signal/output) | Analog EMG output | Teensy pin A0

28. Mount a 3-pin header in the sensor zone for the sensor's cable connector.
29. Solder the VCC pin of the header to the 5V LOGIC strip.
30. Solder the GND pin of the header to the GND strip.
31. Solder the SIG pin of the header to Teensy A0 with a jumper wire.
32. Do not let the SIG wire run parallel and touching alongside a servo power wire for any long stretch — this picks up electrical noise. Keep them separated where possible.

# 11. Step 6 — Wire the Four Servos

Each MG996R servo has three wires: signal (usually orange/yellow), power (usually red), and ground (usually brown/black). Confirm your specific servo's color code with its datasheet before soldering, since colors are not universal.

Servo | PCA9685 Channel | Servo Wire | Connects To
Servo 1 | CH0 | Signal | PCA9685 CH0 signal pin
Servo 1 | CH0 | Power | 6V SERVO strip (via PCA9685 V+ row)
Servo 1 | CH0 | Ground | GND strip
Servo 2 | CH1 | Signal / Power / Ground | Same pattern, channel 1
Servo 3 | CH2 | Signal / Power / Ground | Same pattern, channel 2
Servo 4 | CH3 | Signal / Power / Ground | Same pattern, channel 3

33. Mount four 3-pin headers in the servo zone, one per servo, spaced enough apart that connector plugs do not touch.
34. For each header, solder the signal pin to the matching PCA9685 channel's signal pad.
35. For each header, solder the power pin to the 6V SERVO strip.
36. For each header, solder the ground pin to the GND strip.
37. Double check channel order matches your firmware (CH0, CH1, CH2, CH3 = Servo 1, 2, 3, 4 in the code).

# 12. Step 7 — Full Pre-Power Checklist

Complete every line below with the board fully assembled, but with NOTHING powered on. Use only the multimeter.

# | Check | Expected Result

1 | Continuity: 5V LOGIC strip to GND strip | NO beep (open circuit)
2 | Continuity: 6V SERVO strip to GND strip | NO beep
3 | Continuity: 5V LOGIC strip to 6V SERVO strip | NO beep (these must stay separate)
4 | Continuity: any two GND points on the board | Beep (connected)
5 | Visual: every solder joint is shiny, not dull/cracked | Pass by eye, magnify if possible
6 | Visual: no stray solder blobs bridging adjacent pads | Pass by eye
7 | Visual: PCA9685 OE pin wire goes to GND, not anywhere else | Confirmed
8 | Visual: all 4 servo signal wires go to different channels | Confirmed
9 | Visual: TX/RX between Teensy and WEMOS are crossed, not parallel | Confirmed

Do Not Skip Check 1, 2, and 3

These three catch the most common and most damaging perfboard mistake: a hidden solder bridge shorting power to ground.

If any of these beep when they should not, you have a short. Find it before applying any power.

# 13. Step 8 — First Power-On (Bench Supply, Not Battery)

38. Set the bench power supply to 7.4V output, current limit at 1.0A, OUTPUT OFF.
39. Connect the supply leads to the battery connector pads on the board (where the LiPo will eventually plug in).
40. Turn the output ON. Watch the voltage and current readout for 5 full seconds.
41. If voltage holds steady near 7.4V and current draw is under 300mA with no servos commanded, you are clear.
42. If voltage sags and settles low, turn off immediately. This means current draw is hitting your limit — recheck for a short using the Pre-Power Checklist before trying again.
43. Once stable, measure the 5V LOGIC strip (expect ~5V) and 6V SERVO strip (expect ~6V) with the board live.
44. Only after this passes, connect one servo at a time to its header and recheck current draw stays reasonable (a single idle MG996R draws very little, well under 100mA at rest).

# 14. Step 9 — Upload Firmware and Test

45. Connect the Teensy to your computer via USB and upload the EMG-to-servo control sketch.
46. With the bench supply still powering the board, sit still for the calibration delay at boot. This records your resting EMG baseline.
47. Flex the muscle under the sensor. All four servos should move together, smoothly, with no jitter.
48. Release the flex. Servos should return to rest position without bouncing.
49. Open the Arduino Serial Plotter at 115200 baud to see the live EMG envelope value as a single line, confirming the signal rises on flex and falls on rest.
50. Power the WEMOS C3 Mini, connect to its WiFi access point from a phone or laptop, and open its IP address in a browser to view the live graph.
51. Only after every test above passes on bench power, disconnect the bench supply and connect the 2S LiPo for a final live test.

# 15. Troubleshooting Guide

Symptom | Most Likely Cause | Fix
Servos don't move at all | PCA9685 not found on I2C, or OE not grounded, or code sends zero PWM at boot | Run I2C scanner, confirm 0x40. Confirm OE wired to GND. Add a forced initial PWM write in setup().
Servos jitter constantly | No common ground between PCA9685 and servo power, or noisy EMG signal with no smoothing | Confirm shared GND. Add/raise envelope smoothing and deadband in firmware.
Voltage sags and settles low on power-up | Short circuit, or current limit set too low, or stalled servo drawing high current | Disconnect servos, retest board alone. Raise current limit gradually. Inspect for solder bridges.
Teensy and WEMOS don't communicate | TX/RX wired straight across instead of crossed | Swap so Teensy TX goes to WEMOS RX, and Teensy RX goes to WEMOS TX.
EMG signal flat, never rises on flex | Sensor VCC/GND swapped, or signal wire on wrong analog pin, or electrode placement off-muscle | Recheck wiring against pinout table. Reposition electrodes along the muscle fiber direction.
WiFi page won't load | Not connected to the WEMOS access point, or wrong IP typed | Reconnect phone/laptop WiFi to the WEMOS SSID first, then browse to its printed IP.
Board works on bench supply, fails on battery | LiPo voltage sagging under load, or battery near-empty, or buck converter input range mismatch | Charge battery fully. Confirm buck converter accepts your LiPo's voltage range. Recheck connector polarity.

# 16. Final Assembly and Strain Relief

- Secure every wire that leaves the board (battery, servos, EMG cable) with a small zip tie or tape loop anchored to the board, so a tug on the cable does not pull directly on a solder joint.
- Cover any exposed solder joints near moving parts with heat shrink tubing or electrical tape.
- Label each servo header (1-4) and the EMG cable with a small piece of tape, matching the hand's fingers, so reassembly after transport is fast.
- Before the Innovation Fair demo, repeat the full Pre-Power Checklist one more time. Vibration from transport can crack a marginal joint.
- Bring the bench power supply and multimeter to the demo if possible. If anything misbehaves on-site, you can isolate battery-vs-board issues in seconds.

End of guide. Keep this document with the board for any future repairs or modifications.

ExoHand — Perfboard Assembly Guide

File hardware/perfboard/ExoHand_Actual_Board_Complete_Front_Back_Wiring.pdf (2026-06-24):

Component Side - Complete Fly Wiring

Solder Side - Complete Overview

Solder Side - Power Routes Only

Solder Side - Signal Routes and Fly-Wire Reference

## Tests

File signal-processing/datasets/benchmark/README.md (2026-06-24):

# Benchmark dataset — NinaPro

Files in this folder (`S9_A1_E1.mat`, `S9_A1_E2.mat`, `S9_A1_E3.mat`, `S1_A1_E*_emg.csv`, `S1_A1_E*_restimulus.csv`) are **not collected by Team Orvyn.**

They come from the **NinaPro database** (Ninapro: Non-Invasive Adaptive hand Prosthetics), a public benchmark dataset of surface EMG signals used widely in EMG gesture-classification research.

- Subject codes `S1`, `S9` and exercise codes `E1`/`E2`/`E3` are NinaPro's own naming convention, kept as-is.
- Source: https://ninapro.hevs.ch
- Used here to validate the team's filtering and feature-extraction pipeline (`Filter_signals.py`) against a public reference before relying on the team's own collected EMG data.

Cite the original NinaPro publications if reusing this data outside this project.

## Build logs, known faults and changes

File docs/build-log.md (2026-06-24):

# Build Log — ExoHand (Team Orvyn, Group 19, ECTE351)

Reconstructed from file timestamps, KiCad backup snapshots, and code differences across saved versions. This is the honest version of events, including what didn't work.

## Nov 2025 — PCB design starts

The KiCad project (`Exohand_Updated`) is created on 2025-11-20. This is the start of the custom PCB effort, separate from the perfboard build that comes later. Early backup snapshots from 2026-01-09 and 2026-01-15 show the schematic and footprint placement still being worked out.

## Feb 2026 — first signal processing and first firmware

`Filter_signals.py` (2026-02-02) is the first signal-processing script: bandpass filter (20–450 Hz) + 50 Hz notch filter + RMS windowing, run against the public NinaPro benchmark dataset (`S1_A1_E1/E2/E3` emg + restimulus files) rather than the team's own EMG data. This was the validation step — prove the filtering pipeline works against a known public dataset before trusting data collected in-house.

`Exohand_emg_with_filter.ino` (2026-02-16) is the first firmware. It reads three analog channels (flexor, extensor, "extra"), computes RMS over a 40-sample window, and drives a single servo based on which channel has more activity. No classifier yet — this is straight threshold-based assist control. This version is kept in `firmware/archive/` since it was superseded.

## Mar–Apr 2026 — PCB iteration, simulation

`schematic.cir` / `schematic.json` (2026-03-31) and `Exohand_Updated.net` (2026-04-01) are circuit-simulation and netlist exports. Between 2026-04-12 and 2026-04-22 there are five separate KiCad backup snapshots — this was the heaviest period of board-layout iteration, consistent with working through logic/power plane separation and footprint placement issues. All snapshots are kept in `hardware/schematics/archive/Exohand_Updated-backups/`.

## May 2026 — more PCB revisions, web draft, poster

More KiCad backups land on 2026-05-09 and 2026-05-10. The website draft (`ORVYNUpdated.html` and a `-LOCAL` variant) appears on 2026-05-20.

The poster went through three saves in the space of twelve minutes on 2026-05-24 (07:39, 07:45, 07:51) — `ORVYNS_ExoHand_A1_300dpi.pdf`, then `ORVYN's_Poster.pdf`, then `OrvynExoHand_Poster_A1_300dpi.pdf`. All three are different files (checked by hash, not identical), so all three are kept under `docs/posters/`.

On 2026-05-25, `live_predict.py` appears — a script meant to read live EMG over serial from a Teensy, run a pre-trained Random Forest model, and print the predicted gesture with majority-vote smoothing. Its header comment credits "Antigravity AI Assistant" as author. Worth flagging: it looks for model files named `exohand_rf_model.pkl`, `exohand_label_encoder.pkl`, and `exohand_feature_columns.pkl` — none of which exist anywhere in the project. The actual trained artifacts that do exist are `ExoHand_RF_Model.joblib` and `ExoHand_Scaler.joblib`. As saved, this script would not find its model files. A screen recording from the same day (`Screen Recording 2026-05-25 at 5.38.13 PM.mov`) suggests a live demo was attempted around this point.

## Jun 2026 — more PCB iteration, classifier training, perfboard pivot

Three more KiCad backups land on 2026-06-03, three on 2026-06-11, and one on 2026-06-13 — the final push on the PCB before the team moved to a hand-built perfboard for the actual physical build (see below).

`ExoHand_Build_Manual.docx` appears 2026-06-15.

On 2026-06-16, two assembly-guide documents are saved an hour apart — `ExoHand_Perfboard_Assembly_Guide.docx` and `ExoHand_Perfboard_Assembly_Guide_1.docx` (different content, both kept; `_1` archived). This is the point where the project moves from "we designed a custom PCB" to "we are wiring this on perfboard" — likely a fabrication-time or schedule constraint, since the KiCad PCB work continued in parallel rather than being abandoned outright.

The RF classifier notebook exists in two saves: `ExoHand_EMG_Classifier_RF_V2 (1).ipynb` (2026-06-16) then `ExoHand_EMG_Classifier_RF_V2.ipynb` (2026-06-17) — the second is the one kept as current, the first archived. The trained model and scaler (`ExoHand_RF_Model.joblib`, `ExoHand_Scaler.joblib`) are exported the same day the second notebook run finished.

On 2026-06-18, the `AI_Classifier` working folder is assembled: `exohand_assist_control.ino`, `exohand_emg_test.ino`, an updated `Filter_signals.py`, the latest `.kicad_sch`/`.kicad_pcb`, and fresh copies of the joblib model/scaler (a few minutes newer than the root copies — these are the ones treated as current).

On 2026-06-19, `ExoHand_Teensy.ino` appears — the most advanced firmware in the project. It samples EMG at 1 kHz, extracts ten statistical features per window (MAV, RMS, variance, std dev, waveform length, zero-crossing rate, slope sign changes, skewness, kurtosis, IQR), runs a Random Forest classifier **embedded directly in the firmware as decision trees** (`ai_classifier_model.h`), debounces the classification result, and drives four PCA9685 servo channels (pinky&ring, middle, index, thumb) with smoothed motion. It also streams raw EMG and confirmed gestures over UART1 to an ESP32 for a live graph.

**This was the one real gap in the saved history**: `ai_classifier_model.h` is included by `ExoHand_Teensy.ino`/`teensy_final.ino` but never existed anywhere in the project files — the conversion from the trained `.joblib` Random Forest into C arrays was never saved alongside the firmware. **Resolved**: `signal-processing/export_model_to_header.py` now loads `ExoHand_RF_Model.joblib` + `ExoHand_Scaler.joblib` directly and exports the real tree structure (200 trees, 23,024 nodes, 10 features, 6 classes) and the real scaler mean/scale into `firmware/current/ai_classifier_model.h`. Nothing in the header is invented — every threshold, leaf class, and scaler value comes straight from the trained model files. Re-run the script any time the model is retrained.

One real preprocessing mismatch surfaced while building the export script, worth flagging rather than silently fixing: the training notebook scales every raw sample in a window first (`(x - mean) / scale`, a `StandardScaler` fit on the single raw EMG column) and then computes all 10 features from that scaled window. `teensy_final.ino`'s `extractFeatures()` only applies that same scaling to the MAV feature (it has its own `// only MAV was scaled` comment), leaving RMS/Variance/Std/WL computed on raw, unscaled samples. The exported header faithfully reflects the real trained tree thresholds either way — this note is about the firmware's feature-extraction step potentially not matching what the model was trained on, not about the header. Left as-is since fixing it wasn't part of this pass; worth a look if classification accuracy on real hardware looks off.

On 2026-06-20, the last three files land: `ExoHand_ESP32.ino`, `ExoHand_ServoTest.ino`, and the FastAPI live dashboard (`app.py` + templates/static). `ExoHand_ESP32.ino` is a second, ESP32-targeted version of the servo-only test sketch (it uses explicit `Wire.begin(SDA, SCL)` pins, which Teensy code doesn't need but ESP32 does) — its header comment still says "ExoHand_ServoTest.ino", left over from copy-pasting.

At this point in the history, the dashboard backend (`app.py`) was written for a **Teensy 4.1** specifically (also echoed in `web/dashboard/README.md`, `templates/index.html`, and `esp32_bridge.ino`'s comments), while `ExoHand_Teensy.ino`'s own header comment said **Teensy 4.0**. **Resolved**: the project is standardized on **Teensy 4.0** throughout (it's what the firmware header comments, and the actual board footprint in `hardware/schematics/`, agree on). The `app.py` docstring, its always-"Teensy 4.1" port-label bug (`board = "Teensy 4.1" if ... else "Teensy 4.1"`, a no-op ternary — simplified to a plain `"Teensy 4.0"` literal), the dashboard README, `templates/index.html`, and `esp32_bridge.ino`'s comments were all corrected to say 4.0. This section stays as the historical record of why the inconsistency existed; `README.md`/`architecture.md`/`decisions.md` now state Teensy 4.0 with no hedging.

## Recovered from GitHub history (not present in the local Mac file scan)

The repo's existing git history (`AI_Classifier/.git`, already pointed at `github.com/muhammadmapkar/Exohand_Project`) contained 10 commits past the point this reorganization started from. These commits added four files that never existed anywhere in the local `Documents/ORVYN` folder scanned at the start of this job — they were committed straight to GitHub (likely from a different machine or the GitHub web UI) and never synced back to this Mac:

- **`teensy_final.ino`** (444 lines, vs. 303 in `ExoHand_Teensy.ino`) — a more advanced revision of the same flagship firmware. Its own header comment still says `// ExoHand_Teensy.ino`. Adds a `Watchdog_t4` hardware watchdog, EEPROM-backed calibration/baseline persistence (`EEPROM_MAGIC` check), a heartbeat interval, and confidence-gated classification (`CONFIDENCE_THRESHOLD`) on top of everything `ExoHand_Teensy.ino` already did. It still depends on the same missing `ai_classifier_model.h`. Because it's a strict superset/evolution of `ExoHand_Teensy.ino`, it's treated as current and the older file moves to `firmware/archive/`.
- **`esp32_bridge.ino`** — the actual ESP32 WiFi/telemetry sketch that earlier notes (above, and in `decisions.md`/`architecture.md`) said was missing. It runs a WiFi access point (`WiFi.softAP`, SSID `ExoHand_Live`) plus a WebSocket server (port 81, using the `WebSockets` library by Markus Sattler) that bridges serial data from the Teensy (`Serial2`, pins 16/17) straight to a browser. This resolves the gap — the bridge firmware exists, it just wasn't saved into the local project folder.
- **`website.html`** (4262 lines, vs. 3208 in `ORVYNUpdated.html`) — a substantially more developed version of the site: a black/orange "Armory" visual theme, a "Live Rehab" dashboard view (metrics, per-patient goals, control panel), a live EMG chart (Chart.js) presumably fed by `esp32_bridge.ino`'s WebSocket, a camera-based sensor-placement assistant using MediaPipe FaceMesh, and a light Supabase integration. This supersedes `ORVYNUpdated.html`, which moves to `web/archive/`.
- **`exohand_demo.mp4`** — a demo video, added to `media/`.

`web/dashboard/app.py` was also touched in this history (Teensy 4.0 docstring, simpler serial-value parsing), but the copy already pulled from the Mac (which said Teensy 4.1 at the time, and handles comma-separated multi-channel serial lines) is newer than this remote version, so the local copy was kept as current; its 4.1 references were corrected to 4.0 in a later pass (see above).

## Summary of what's "current" vs "archive"

Current: `teensy_final.ino` (flagship classifier firmware, supersedes `ExoHand_Teensy.ino`), `esp32_bridge.ino` (WiFi/WebSocket telemetry bridge), `ExoHand_ESP32.ino`, `ExoHand_ServoTest.ino`, `exohand_assist_control.ino`, `exohand_emg_test.ino`, the 2026-06-17 notebook, the AI_Classifier-folder joblib model/scaler, the latest KiCad sch/pcb, the perfboard guide (non-`_1`), `website.html` (supersedes `ORVYNUpdated.html`), the FastAPI dashboard.

Archived (kept, not deleted): `ExoHand_Teensy.ino` (superseded by `teensy_final.ino`), `Exohand_emg_with_filter.ino` (early single-servo RMS firmware), the duplicate notebook save, root-level joblib duplicates, `ORVYNUpdated.html` and `ORVYNUpdated-LOCAL.html` (superseded by `website.html`), the `_1` perfboard guide, the packaged dashboard zip, every dated KiCad backup snapshot (20 of them), and duplicate dataset copies found in alternate folders.

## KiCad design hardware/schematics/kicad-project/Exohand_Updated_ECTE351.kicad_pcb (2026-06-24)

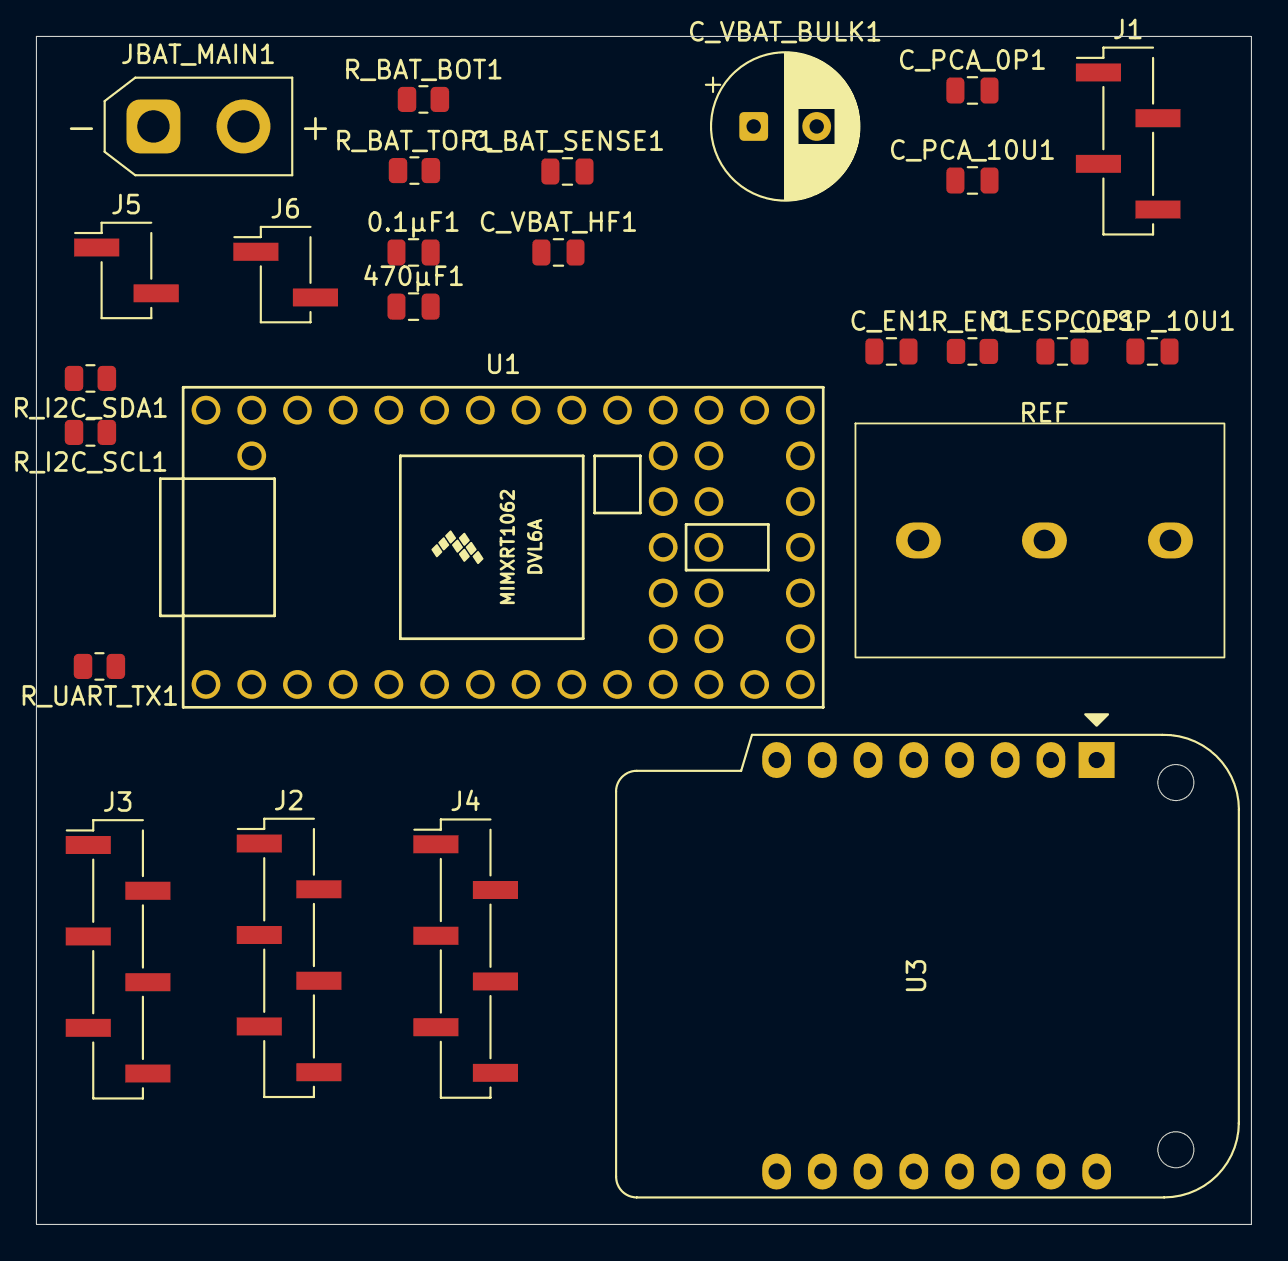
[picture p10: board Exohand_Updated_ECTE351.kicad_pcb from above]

Board: 2 copper layers, 67.5 x 66.0 mm, 26 parts (0 on the bottom side), 14 nets, no tracks yet.

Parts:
0.1µF1, 470µF1: C; C_0805_2012Metric
C_BAT_SENSE1: C; C_0805_2012Metric
C_EN1: C; C_0805_2012Metric
C_ESP_0P1, C_ESP_10U1: C; C_0805_2012Metric
C_PCA_0P1, C_PCA_10U1: C; C_0805_2012Metric
C_VBAT_BULK1: C_Polarized; CP_Radial_D8.0mm_P3.50mm
C_VBAT_HF1: C; C_0805_2012Metric
J1: Conn_01x04_Pin; PinHeader_1x04_P2.54mm_Vertical_SMD_Pin1Left
J2, J3, J4: Conn_01x05_Pin; PinHeader_1x06_P2.54mm_Vertical_SMD_Pin1Left
J5, J6: Conn_01x02_Pin; PinHeader_1x02_P2.54mm_Vertical_SMD_Pin1Left
JBAT_MAIN1: Conn_01x02; AMASS_XT30UPB-F_1x02_P5.0mm_Vertical
R_BAT_BOT1: R; R_0805_2012Metric
R_BAT_TOP1: R; R_0805_2012Metric
R_EN1: R; R_0805_2012Metric
R_I2C_SCL1, R_I2C_SDA1: R; R_0805_2012Metric
R_UART_TX1: R; R_0805_2012Metric
SW1: SW_SPST; KCD1-101
U1: Teensy4.0; Teensy40
U3: WEMOS_C3_mini

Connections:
3V3: C_EN1.1, C_ESP_0P1.1, C_ESP_10U1.1, C_PCA_0P1.1, C_PCA_10U1.1, J2.5, J3.5, J4.5, R_EN1.1, R_I2C_SCL1.1, R_I2C_SDA1.1, U3.8 (3V3)
5V_LOGIC: 0.1µF1.2, 470µF1.2, J1.2, U1.33 (VIN)
EMG1_SIG: J2.2, U1.21 (14_A0_TX3_SPDIF_OUT)
EMG2_SIG: J3.2, U1.22 (15_A1_RX3_SPDIF_IN)
EMG3_SIG: J4.2, U1.23 (16_A2_RX4_SCL1)
ESP_EN: R_EN1.2, U3.1 (EN)
ESP_TX: R_UART_TX1.1, U1.3 (1_TX1_CTX2_MISO1), U3.15 (RX)
ESP_TX_RAW: R_UART_TX1.2, U1.2 (0_RX1_CRX2_CS1), U3.16 (TX)
GND: 0.1µF1.1, 470µF1.1, C_BAT_SENSE1.2, C_EN1.2, C_ESP_0P1.2, C_ESP_10U1.2, C_PCA_0P1.2, C_PCA_10U1.2, C_VBAT_BULK1.2, C_VBAT_HF1.2, J1.1, J2.3, J2.4, J3.3, J3.4, J4.3, J4.4, J5.2, J6.2, JBAT_MAIN1.2, R_BAT_BOT1.2, U1.32 (GND), U3.10 (GND)
I2C_SCL: J1.4, R_I2C_SCL1.2, U1.26 (19_A5_SCL0)
I2C_SDA: J1.3, R_I2C_SDA1.2, U1.25 (18_A4_SDA0)
VBAT: C_VBAT_BULK1.1, C_VBAT_HF1.1, J5.1, R_BAT_TOP1.1, SW1.2 (B)
VBAT_RAW: JBAT_MAIN1.1, SW1.1 (A)
VBAT_SENSE: C_BAT_SENSE1.1, R_BAT_BOT1.1, R_BAT_TOP1.2, U3.5 (D0)

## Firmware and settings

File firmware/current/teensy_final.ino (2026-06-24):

// ExoHand_Teensy.ino
  // Teensy 4.0 — EMG capture, feature extraction, embedded RF classifier,
  // servo drive via PCA9685, UART bridge to ESP32, safety + diagnostics.
  //
  // Libraries needed (Library Manager):
  //   Adafruit PWM Servo Driver Library
  //   Watchdog_t4 (bundled with Teensyduino — no install needed)
  //   EEPROM (built-in)
  //
  // EMG sensor (SEN0240) -> A0
  // I2C: SDA=18, SCL=19  (PCA9685 @0x40)
  // UART1 to WEMOS C3: TX1(pin1)->ESP RX, RX1(pin0)->ESP TX
  
  #include <Wire.h>
  #include <Adafruit_PWMServoDriver.h>
  #include <EEPROM.h>
  #include <Watchdog_t4.h>
  #include "ai_classifier_model.h"
  
  // ---------------- CONFIG ----------------
  #define EMG_PIN A0
  #define SAMPLE_RATE_HZ   1000
  #define WINDOW_SIZE      30
  #define STEP_SIZE        5
  
  #define SCALER_MEAN      463.59002976f
  #define SCALER_SCALE     15.98672036f
  
  Adafruit_PWMServoDriver pwm = Adafruit_PWMServoDriver(0x40);
  #define PCA_OSC_FREQ     27000000
  #define SERVO_FREQ_HZ    50
  
  #define CH_PINKY_RING    0
  #define CH_MIDDLE        1
  #define CH_INDEX         2
  #define CH_THUMB         3
  
  #define SERVO_PULSE_MIN  102
  #define SERVO_PULSE_MAX  512
  
  float SERVO_OPEN_ANGLE[4]   = {0, 0, 0, 0};
  float SERVO_CLOSED_ANGLE[4] = {180, 180, 180, 180};
  
  #define SERVO_STEP_DEG     3.0f
  #define SERVO_UPDATE_MS    15
  
  #define CONFIRM_COUNT      4
  #define MIN_HOLD_MS        150
  #define CONFIDENCE_THRESHOLD 0.40f   // below this, treat as "no change"
  
  #define EMG_SEND_INTERVAL_MS  20
  #define HEARTBEAT_INTERVAL_MS 500
  #define CONFIDENCE_SEND_MS    200
  
  // Baseline calibration
  #define BASELINE_CAPTURE_MS 1000
  
  // EEPROM
  #define EEPROM_MAGIC 0xA5
  
  // Watchdog
  WDT_T4<WDT1> wdt;
  #define WDT_TIMEOUT_S 2
  
  // ---------------- STATE ----------------
  volatile int sampleBuf[WINDOW_SIZE];
  volatile int bufHead = 0;
  volatile int samplesSinceClassify = 0;
  volatile bool bufFull = false;
  volatile int lastRawSample = 0;
  
  IntervalTimer sampleTimer;
  
  float currentAngle[4];
  float targetAngle[4];
  unsigned long lastServoUpdate = 0;
  
  char confirmedGesture[16] = "rest";
  char history[CONFIRM_COUNT][16];
  int historyIdx = 0;
  unsigned long lastGestureChange = 0;
  
  unsigned long lastEmgSend = 0;
  unsigned long lastHeartbeat = 0;
  unsigned long lastConfidenceSend = 0;
  
  float restBaselineMAV = 0;
  float lastConfidence = 0;
  
  struct CalibData {
    uint8_t magic;
    float openAngle[4];
    float closedAngle[4];
  };
  
  // ---------------- ISR: 1kHz sampling ----------------
  void sampleISR() {
    int v = analogRead(EMG_PIN);
    lastRawSample = v;
    sampleBuf[bufHead] = v;
    bufHead = (bufHead + 1) % WINDOW_SIZE;
    samplesSinceClassify++;
    if (bufHead == 0) bufFull = true;
  }
  
  // ---------------- Feature extraction ----------------
  void getOrderedWindow(int out[WINDOW_SIZE]) {
    noInterrupts();
    int head = bufHead;
    for (int i = 0; i < WINDOW_SIZE; i++) {
      out[i] = sampleBuf[(head + i) % WINDOW_SIZE];
    }
    interrupts();
  }
  
  void extractFeatures(int w[WINDOW_SIZE], float feat[RF_NUM_FEATURES]) {
    float mean = 0;
    for (int i = 0; i < WINDOW_SIZE; i++) mean += w[i];
    mean /= WINDOW_SIZE;
  
    float mav = 0, sumSq = 0, wl = 0;
    for (int i = 0; i < WINDOW_SIZE; i++) {
      mav += fabsf(w[i]);
      sumSq += (float)w[i] * w[i];
    }
    mav /= WINDOW_SIZE;
    float rms = sqrtf(sumSq / WINDOW_SIZE);
  
    for (int i = 0; i < WINDOW_SIZE - 1; i++) wl += fabsf(w[i + 1] - w[i]);
  
    float variance = 0;
    for (int i = 0; i < WINDOW_SIZE; i++) {
      float d = w[i] - mean;
      variance += d * d;
    }
    variance /= WINDOW_SIZE;
    float stddev = sqrtf(variance);
  
    int zcr = 0;
    for (int i = 0; i < WINDOW_SIZE - 1; i++) {
      float a = w[i] - mean, b = w[i + 1] - mean;
      if (a * b < 0) zcr++;
    }
  
    int ssc = 0;
    for (int i = 1; i < WINDOW_SIZE - 1; i++) {
      float d1 = (float)w[i] - w[i - 1];
      float d2 = (float)w[i + 1] - w[i];
      if (d1 * d2 < 0) ssc++;
    }
  
    float skew = 0, kurt = 0;
    if (stddev > 0.0001f) {
      for (int i = 0; i < WINDOW_SIZE; i++) {
        float z = (w[i] - mean) / stddev;
        skew += z * z * z;
        kurt += z * z * z * z;
      }
      skew /= WINDOW_SIZE;
      kurt = (kurt / WINDOW_SIZE) - 3.0f;
    }
  
    int sorted[WINDOW_SIZE];
    for (int i = 0; i < WINDOW_SIZE; i++) sorted[i] = w[i];
    for (int i = 1; i < WINDOW_SIZE; i++) {
      int key = sorted[i], j = i - 1;
      while (j >= 0 && sorted[j] > key) {
        sorted[j + 1] = sorted[j];
        j--;
      }
      sorted[j + 1] = key;
    }
    auto percentile = [&](float p) -> float {
      float idx = p * (WINDOW_SIZE - 1);
      int lo = (int)idx;
      int hi = lo + 1 < WINDOW_SIZE ? lo + 1 : lo;
      float frac = idx - lo;
      return sorted[lo] + frac * (sorted[hi] - sorted[lo]);
    };
    float iqr = percentile(0.75f) - percentile(0.25f);
  
    feat[0] = (mav - SCALER_MEAN) / SCALER_SCALE;
    feat[1] = rms;
    feat[2] = variance;
    feat[3] = stddev;
    feat[4] = wl;
    feat[5] = (float)zcr;
    feat[6] = (float)ssc;
    feat[7] = skew;
    feat[8] = kurt;
    feat[9] = iqr;
  }
  
  // ---------------- RF inference (hard majority vote + confidence) ----------------
  int predictTree(int treeIdx, float feat[RF_NUM_FEATURES]) {
    int16_t idx = RF_TREE_ROOTS[treeIdx];
    while (RF_NODES[idx].feature != -1) {
      if (feat[RF_NODES[idx].feature] <= RF_NODES[idx].threshold)
        idx = RF_NODES[idx].left;
      else
        idx = RF_NODES[idx].right;
    }
    return RF_NODES[idx].leaf_class;
  }
  
  int classify(float feat[RF_NUM_FEATURES], float* confidenceOut) {
    int votes[RF_NUM_CLASSES] = {0};
    for (int t = 0; t < RF_NUM_TREES; t++) votes[predictTree(t, feat)]++;
    int best = 0;
    for (int c = 1; c < RF_NUM_CLASSES; c++) if (votes[c] > votes[best]) best = c;
    if (confidenceOut) *confidenceOut = (float)votes[best] / RF_NUM_TREES;
    return best;
  }
  
  // ---------------- Debounce ----------------
  void pushHistory(const char* label) {
    strncpy(history[historyIdx], label, 15);
    historyIdx = (historyIdx + 1) % CONFIRM_COUNT;
  }
  
  bool historyAllAgree(const char* label) {
    for (int i = 0; i < CONFIRM_COUNT; i++) {
      if (strcmp(history[i], label) != 0) return false;
    }
    return true;
  }
  
  // ---------------- Gesture -> servo targets ----------------
  void applyGestureTargets(const char* g) {
    for (int i = 0; i < 4; i++) targetAngle[i] = SERVO_OPEN_ANGLE[i];
  
    if (strcmp(g, "fist") == 0) {
      for (int i = 0; i < 4; i++) targetAngle[i] = SERVO_CLOSED_ANGLE[i];
    } else if (strcmp(g, "pinky&ring") == 0) {
      targetAngle[CH_PINKY_RING] = SERVO_CLOSED_ANGLE[CH_PINKY_RING];
    } else if (strcmp(g, "middle") == 0) {
      targetAngle[CH_MIDDLE] = SERVO_CLOSED_ANGLE[CH_MIDDLE];
    } else if (strcmp(g, "index") == 0) {
      targetAngle[CH_INDEX] = SERVO_CLOSED_ANGLE[CH_INDEX];
    } else if (strcmp(g, "thumb") == 0) {
      targetAngle[CH_THUMB] = SERVO_CLOSED_ANGLE[CH_THUMB];
    }
  }
  
  void writeServoAngle(int ch, float angle) {
    int pulse = (int)(SERVO_PULSE_MIN + (angle / 180.0f) * (SERVO_PULSE_MAX - SERVO_PULSE_MIN));
    pwm.setPWM(ch, 0, pulse);
  }
  
  void updateServosSmooth() {
    if (millis() - lastServoUpdate < SERVO_UPDATE_MS) return;
    lastServoUpdate = millis();
    for (int i = 0; i < 4; i++) {
      float diff = targetAngle[i] - currentAngle[i];
      if (fabsf(diff) <= SERVO_STEP_DEG) {
        currentAngle[i] = targetAngle[i];
      } else {
        currentAngle[i] += (diff > 0 ? SERVO_STEP_DEG : -SERVO_STEP_DEG);
      }
      writeServoAngle(i, currentAngle[i]);
    }
  }
  
  // ---------------- EEPROM calibration ----------------
  void saveCalibration() {
    CalibData c;
    c.magic = EEPROM_MAGIC;
    for (int i = 0; i < 4; i++) {
      c.openAngle[i] = SERVO_OPEN_ANGLE[i];
      c.closedAngle[i] = SERVO_CLOSED_ANGLE[i];
    }
    EEPROM.put(0, c);
    Serial.println("Calibration saved");
  }
  
  void loadCalibration() {
    CalibData c;
    EEPROM.get(0, c);
    if (c.magic == EEPROM_MAGIC) {
      for (int i = 0; i < 4; i++) {
        SERVO_OPEN_ANGLE[i] = c.openAngle[i];
        SERVO_CLOSED_ANGLE[i] = c.closedAngle[i];
      }
      Serial.println("Calibration loaded from EEPROM");
    } else {
      saveCalibration();
      Serial.println("No calibration found, defaults saved");
    }
  }
  
  // Serial commands: "O0 15" open ch0=15 | "C3 170" closed ch3=170 | "SAVE" | "PRINT"
  void handleSerialCommands() {
    if (!Serial.available()) return;
    String cmd = Serial.readStringUntil('\n');
    cmd.trim();
    if (cmd.length() < 2) return;
  
    if (cmd == "SAVE") {
      saveCalibration();
      return;
    }
    if (cmd == "PRINT") {
      for (int i = 0; i < 4; i++) {
        Serial.print("CH"); Serial.print(i);
        Serial.print(" open="); Serial.print(SERVO_OPEN_ANGLE[i]);
        Serial.print(" closed="); Serial.println(SERVO_CLOSED_ANGLE[i]);
      }
      return;
    }
  
    char type = cmd.charAt(0);
    int ch = cmd.charAt(1) - '0';
    int spaceIdx = cmd.indexOf(' ');
    if ((type == 'O' || type == 'C') && ch >= 0 && ch < 4 && spaceIdx > 0) {
      float angle = cmd.substring(spaceIdx + 1).toFloat();
      if (type == 'O') SERVO_OPEN_ANGLE[ch] = angle;
      else SERVO_CLOSED_ANGLE[ch] = angle;
      Serial.print("Set "); Serial.print(type); Serial.print(ch);
      Serial.print(" = "); Serial.println(angle);
    }
  }
  
  // ---------------- Baseline auto-calibration ----------------
  void captureBaseline() {
    Serial.println("Capturing rest baseline, keep hand relaxed...");
    unsigned long start = millis();
    long sum = 0;
    int count = 0;
    while (millis() - start < BASELINE_CAPTURE_MS) {
      sum += analogRead(EMG_PIN);
      count++;
      delay(1);
    }
    restBaselineMAV = (float)sum / count;
    Serial.print("Baseline MAV: "); Serial.println(restBaselineMAV);
  }
  
  // ---------------- Startup sweep test ----------------
  void sweepTest() {
    Serial.println("Servo sweep test...");
    for (int i = 0; i < 4; i++) {
      writeServoAngle(i, SERVO_CLOSED_ANGLE[i]);
      delay(300);
      writeServoAngle(i, SERVO_OPEN_ANGLE[i]);
      delay(300);
    }
    Serial.println("Sweep test done");
  }
  
  // ---------------- Setup ----------------
  void setup() {
    Serial.begin(115200);
    Serial1.begin(115200);
  
    analogReadResolution(10);
  
    Wire.begin();
    pwm.begin();
    pwm.setOscillatorFrequency(PCA_OSC_FREQ);
    pwm.setPWMFreq(SERVO_FREQ_HZ);
  
    loadCalibration();
  
    for (int i = 0; i < 4; i++) {
      currentAngle[i] = SERVO_OPEN_ANGLE[i];
      targetAngle[i] = SERVO_OPEN_ANGLE[i];
    }
    delay(200);
    for (int i = 0; i < 4; i++) writeServoAngle(i, currentAngle[i]);
  
    sweepTest();
    captureBaseline();
  
    for (int i = 0; i < CONFIRM_COUNT; i++) strncpy(history[i], "rest", 15);
  
    WDT_timings_t config;
    config.trigger = 1;
    config.timeout = WDT_TIMEOUT_S;
    wdt.begin(config);
  
    sampleTimer.begin(sampleISR, 1000000 / SAMPLE_RATE_HZ);
  }
  
  // ---------------- Loop ----------------
  void loop() {
    wdt.feed();
    handleSerialCommands();
  
    if (bufFull && samplesSinceClassify >= STEP_SIZE) {
      noInterrupts();
      samplesSinceClassify = 0;
      interrupts();
  
      int window[WINDOW_SIZE];
      getOrderedWindow(window);
  
      float feat[RF_NUM_FEATURES];
      extractFeatures(window, feat);
  
      float confidence;
      int classIdx = classify(feat, &confidence);
      lastConfidence = confidence;
  
      const char* label = RF_CLASS_NAMES[classIdx];
      if (confidence < CONFIDENCE_THRESHOLD) label = confirmedGesture;
  
      pushHistory(label);
      if (historyAllAgree(label) &&
          strcmp(label, confirmedGesture) != 0 &&
          millis() - lastGestureChange > MIN_HOLD_MS) {
        strncpy(confirmedGesture, label, 15);
        lastGestureChange = millis();
        applyGestureTargets(confirmedGesture);
  
        Serial1.print("G,");
        Serial1.println(confirmedGesture);
      }
    }
    updateServosSmooth();
  
    if (millis() - lastEmgSend >= EMG_SEND_INTERVAL_MS) {
      lastEmgSend = millis();
      // Legacy UART bridge to the ESP32 (harmless if the ESP32 is absent/fried).
      Serial1.print("E,");
      Serial1.println(lastRawSample);
      // USB Serial: emit the raw EMG sample as a plain number, one per line.
      // This drives BOTH the Teensyduino Serial Plotter graph AND the website's
      // Web Serial reader (parsePlotterLine -> feedPlotter mirrors this exact
      // waveform on the live chart). Keep this line numbers-only so the Serial
      // Plotter trace stays clean.
      Serial.println(lastRawSample);
    }
  
    if (millis() - lastHeartbeat >= HEARTBEAT_INTERVAL_MS) {
      lastHeartbeat = millis();
      Serial1.print("H,");
      Serial1.println(millis());
    }
  
    if (millis() - lastConfidenceSend >= CONFIDENCE_SEND_MS) {
      lastConfidenceSend = millis();
      Serial1.print("C,");
      Serial1.println((int)(lastConfidence * 100));
    }
  }

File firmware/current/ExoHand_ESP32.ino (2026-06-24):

// ExoHand_ServoTest.ino
// Pure servo test - no EMG. Cycles each servo individually, then all
// four together, on a loop. Use this to confirm wiring/channels before
// touching EMG logic at all.

#include <Wire.h>
#include <Adafruit_PWMServoDriver.h>

#define I2C_SDA 21
#define I2C_SCL 22

Adafruit_PWMServoDriver pwm = Adafruit_PWMServoDriver(0x40);
#define PCA_OSC_FREQ 27000000
#define SERVO_FREQ_HZ 50
#define NUM_SERVOS 4
#define SERVO_PULSE_MIN 102
#define SERVO_PULSE_MAX 512
#define OPEN_ANGLE   0
#define CLOSED_ANGLE 180

// channel order: 0=pinky&ring, 1=middle, 2=index, 3=thumb
const char* servoNames[NUM_SERVOS] = {"pinky&ring", "middle", "index", "thumb"};

void writeServoAngle(int ch, float angle) {
  int pulse = (int)(SERVO_PULSE_MIN + (angle / 180.0f) * (SERVO_PULSE_MAX - SERVO_PULSE_MIN));
  pwm.setPWM(ch, 0, pulse);
}

void setup() {
  Serial.begin(115200);
  Wire.begin(I2C_SDA, I2C_SCL);
  pwm.begin();
  pwm.setOscillatorFrequency(PCA_OSC_FREQ);
  pwm.setPWMFreq(SERVO_FREQ_HZ);

  for (int i = 0; i < NUM_SERVOS; i++) writeServoAngle(i, OPEN_ANGLE);
  delay(500);
}

void loop() {
  // Test each servo one at a time
  for (int i = 0; i < NUM_SERVOS; i++) {
    Serial.print("Testing channel "); Serial.print(i);
    Serial.print(" ("); Serial.print(servoNames[i]); Serial.println(")");

    writeServoAngle(i, CLOSED_ANGLE);
    delay(600);
    writeServoAngle(i, OPEN_ANGLE);
    delay(600);
  }

  // Then all four together
  Serial.println("Testing all four together");
  for (int i = 0; i < NUM_SERVOS; i++) writeServoAngle(i, CLOSED_ANGLE);
  delay(800);
  for (int i = 0; i < NUM_SERVOS; i++) writeServoAngle(i, OPEN_ANGLE);
  delay(800);

  Serial.println("--- loop complete ---");
  delay(1000);
}

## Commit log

2026-06-19 Add ORVYN dashboard website with live EMG Serial Plotter mirror
    - website.html: ORVYN rehab dashboard (patients, live rehab, history, calibration)
    - Live USB Serial Plotter mirror: parses raw EMG32 serial lines like the Arduino
    Serial Plotter and draws the same waveform live on the rehab view
    - Baud-rate selector on the hardware panel (9600-500000), persisted
    - Rehab waveform plots the true full-range RMS envelope (no clip/round)
    - Non-Patient-1 activity is driven only by live EMG; idle state when no signal
    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
2026-06-19 Live Rehab: gesture panels, per-patient goals, live EMG signal card
    - Replace Current Exercise Guidance + Live EMG Waveform with 4 panels:
    Predicted Gesture, Live EMG Signal (keeps live EMG32 serial feed),
    Signal Statistics, Gesture History (self-contained, rule-based)
    - Rehab goal progress is now per-patient; new patients start at 0,
    Patient 1 keeps its demo numbers; progress persists per patient
    - New patients auto-named "Patient N"; migrate legacy "New Patient"
2026-06-19 Add teensy_final.ino: stream raw EMG over USB Serial for live website graph
    Mirror the raw EMG sample to USB Serial (Serial.println) in addition to the
    legacy Serial1 UART bridge. With the ESP32 dead, this lets the website's Web
    Serial reader (parsePlotterLine/feedPlotter) and the Teensyduino Serial
    Plotter both display the same EMG waveform directly from the Teensy.
2026-06-19 Match live plotter window to Teensyduino Serial Plotter (500 points)
    Change PLOTTER.win from 600 to 500 so the website's live USB EMG waveform
    spans the same number of samples as the Teensyduino Serial Plotter, aligning
    the horizontal scale of the two graphs.
2026-06-19 Use portable relative paths for model artefacts in dashboard
    Replace the hardcoded macOS absolute paths (/Users/muhammadnazirahmedmapkar/
    Documents/...) with os.path.join(PARENT_DIR, ...) so the FastAPI dashboard
    loads ExoHand_RF_Model.joblib / ExoHand_Scaler.joblib relative to the repo on
    any machine.
    [app.py]
2026-06-20 Re-commit ORVYN website.html (no content change)
    Confirm editorial-noir website.html is current on Exohand_Project.
2026-06-20 Add ExoHand device demo video
    Add watermark-removed exoskeleton hand device demo (mp4).
2026-06-20 Wire demo video into hero, rename to exohand_demo.mp4
    Replace the broken scroll-scrubbed frame sequence (referenced missing
    frames/*.jpg) with the real demo video, scrubbed by scroll position with
    eased seeking. Rename the mp4 to exohand_demo.mp4.
2026-06-20 Fix Web Serial parser for Teensy raw samples and add ESP32 bridge code
    [esp32_bridge.ino]
2026-06-24 chore: remove old AI_Classifier flat-layout paths (superseded by exohand/ structure)
    [Exohand_Updated.kicad_pcb, Exohand_Updated.kicad_sch, exohand_emg_dataset.csv]
2026-06-24 feat(firmware): add current + archived Teensy/ESP32 firmware sketches
2026-06-24 feat(hardware): add KiCad schematics/PCB (+20 backups), BOM, perfboard docs
    [Exohand_Updated.csv, Exohand_Updated.kicad_pcb, Exohand_Updated.kicad_sch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]
2026-06-24 feat(signal-processing): add filtering pipeline, RF classifier, model artifacts, datasets (benchmark/collected/processed)
    [Dataset-3.csv, Dataset-Chiranya.xlsx, Dataset-Chiranya_normalized.csv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]
2026-06-24 feat: pull in firmware/web files from GitHub history not present locally
    - teensy_final.ino supersedes ExoHand_Teensy.ino (watchdog, EEPROM, heartbeat)
    - esp32_bridge.ino: actual WiFi/WebSocket telemetry bridge (fills prior gap)
    - website.html supersedes ORVYNUpdated.html (Live Rehab view, live chart, FaceMesh placement assist)
    - exohand_demo.mp4 added to media/
    - docs corrected to remove now-stale 'ESP32 bridge not found' notes
    [ExoHand_Teensy.ino, esp32_bridge.ino, teensy_final.ino]
2026-06-24 Generate missing ai_classifier_model.h from trained model
    - Add signal-processing/export_model_to_header.py: loads
    ExoHand_RF_Model.joblib + ExoHand_Scaler.joblib and exports the real
    trained Random Forest (200 trees, 23024 nodes, 10 features, 6 classes)
    and the real EMG scaler (mean/scale) as plain C arrays + a standalone
    tree-walk inference helper. No invented values -- everything is read
    directly from the joblib files, matching the feature order/scaling
    used in ExoHand_EMG_Classifier_RF_V2.ipynb (the notebook that actually
    produced these joblib files; live_predict.py uses an unrelated,
    disconnected 8-feature pipeline and was not used as the reference).
    - Run it to generate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
    [export_model_to_header.py]
2026-06-24 Standardize on Teensy 4.0 everywhere, resolve 4.0/4.1 contradiction
    Project hardware is Teensy 4.0 (matches the firmware's own header comments
    and the schematics). Removed every '4.1' reference that had crept into the
    dashboard/web side:
    - README.md, docs/architecture.md: state Teensy 4.0 plainly, no hedging.
    - web/dashboard/app.py: docstring corrected; fixed the always-'Teensy 4.1'
    port-label ternary (both branches returned the same string -- a no-op
    bug) to a plain 'Teensy 4.0' literal.
    - web/dashboard/README.md, templates/index.html: 'Teensy 4.1' -> 'Teensy 4.0'.
    - firmware/current/esp32_bridge.ino: comments corrected to 4.0.
    docs/build-log.md is now the only place narrating the his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
    [app.py, esp32_bridge.ino]

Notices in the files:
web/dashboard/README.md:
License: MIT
